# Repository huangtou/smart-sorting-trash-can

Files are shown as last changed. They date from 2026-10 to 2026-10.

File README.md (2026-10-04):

<div align="center">

# 智能分类垃圾桶系统

**基于 STM32F407 + YOLOv5 视觉识别的自动垃圾分类装置**







</div>

---

## 整机工作演示

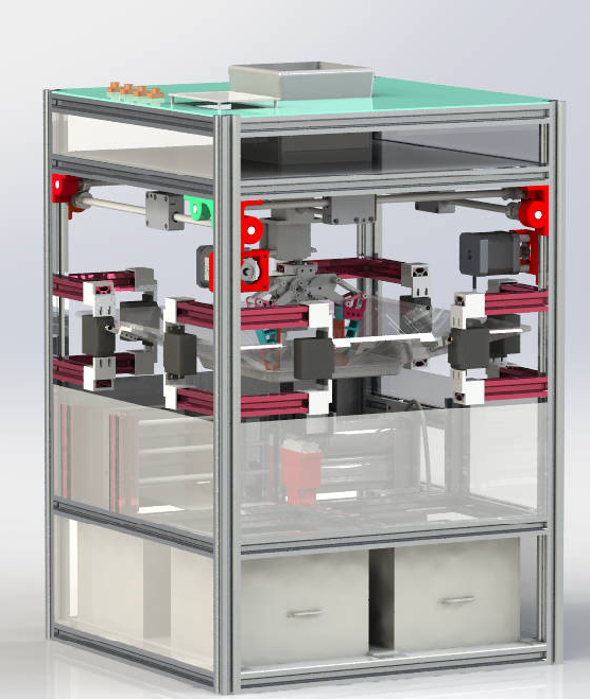
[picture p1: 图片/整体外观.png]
▶ 点击观看：垃圾分类演示视频（B站） (https://www.bilibili.com/video/BV1tyH76QEtr/)


**▶ [点击观看：垃圾分类演示视频（B站）](https://www.bilibili.com/video/BV1tyH76QEtr/)**

> 演示视频已上传 B 站，点击上方封面或链接即可在线观看；完整图文见 [十、效果展示](#十效果展示)。

---

## 目录

- [一、项目简介](#一项目简介)
- [二、主要功能](#二主要功能)
- [三、系统总体方案](#三系统总体方案)
- [四、硬件系统](#四硬件系统)
- [五、机械结构](#五机械结构)
- [六、软件架构](#六软件架构)
- [七、通信协议](#七通信协议)
- [八、快速开始](#八快速开始)
- [九、参数标定与调试](#九参数标定与调试)
- [十、效果展示](#十效果展示)
- [十一、常见问题](#十一常见问题)
- [十二、后续优化方向](#十二后续优化方向)

---

## 一、项目简介

本项目是一套面向**工程实践与创新能力大赛（工创赛）垃圾分类命题**的完整解决方案，实现"投放 → 识别 → 分拣 → 归仓 → 计数"的全流程自动化。

装置由 **视觉识别模块**、**STM32 主控**、**二维移动平台 + 机械臂**、**四分类仓** 与 **压缩机构** 组成：摄像头采集投入物图像，运行 YOLOv5 目标检测得到**垃圾类别**与**目标中心点坐标**，通过串口下发给 STM32；主控解算后根据场景选择**倾倒式投放**（单个物体）或**机械臂抓取投放**（多个物体），将垃圾投入对应的四分类仓，并实时累计各类垃圾数量。

仓库包含 **嵌入式控制程序、视觉识别程序、三维建模图纸、装配与调试资料**，可支撑从结构设计、加工装配到软件联调的完整复现。

---

## 二、主要功能

| 功能 | 说明 |
| :--- | :--- |
| **视觉自动识别** | 基于 YOLOv5 的目标检测，输出垃圾类别 ID 与目标中心点像素坐标 |
| **四分类自动分拣** | 有害垃圾 / 可回收垃圾 / 厨余垃圾 / 其他垃圾 四类自动归仓 |
| **双投放策略** | 单物体采用**翻板倾倒**，多物体采用**机械臂抓取**，兼顾效率与成功率 |
| **二维精确定位** | 由 2 路闭环步进电机驱动 XY 平台，将图像坐标解算为物理坐标并移动到位 |
| **闭环步进驱动** | 通过 CAN 总线控制 Emm_V5 闭环步进电机，支持双机同步运动 |
| **多自由度机械臂** | PCA9685 输出 16 路 PWM，驱动 9 路舵机完成回转 / 升降 / 夹取 / 翻板动作 |
| **分类计数与状态反馈** | 主控实时累计四类垃圾数量，并通过调试串口输出运行状态 |
| **压缩机构（预留）** | TIM4 双路 PWM + 方向 IO + 光电限位，用于桶内垃圾压缩与到位检测 |
| **一键启动** | 独立按键触发投放流程，便于现场演示与调试 |

---

## 三、系统总体方案

### 3.1 系统架构

```
┌──────────────┐   USART3(9600)    ┌──────────────────┐
│              │  类别/坐标/数量    │                  │
│  MaixCam     │ ────────────────► │   STM32F407ZGT6  │
│  视觉模块     │ ◄────────────────  │     主控          │
│ (YOLOv5)     │   请求指令 "FS"    │                  │
└──────────────┘                   └────────┬─────────┘
                                            │
             ┌──────────────────────────────┼──────────────────────────┐
             │                              │                          │
      CAN1(500kbps)                  软件 I2C(PC7/PC8)          TIM4 PWM + GPIO
             │                              │                          │
    ┌────────▼────────┐          ┌──────────▼─────────┐      ┌─────────▼────────┐
    │ Emm_V5 闭环步进  │          │     PCA9685        │      │  压缩机构 / 限位   │
    │  #1  #2 (X/Y)   │          │  16 路 PWM 舵机板   │      │  光电开关 ×3      │
    └────────┬────────┘          └──────────┬─────────┘      └──────────────────┘
             │                              │
      XY 二维移动平台              机械臂(升降/回转/夹爪) + 分类翻板 + 仓盖
```

### 3.2 工作时序

```
上电
 │
 ├─ 外设初始化：GPIO / DMA / USART1 / USART3 / TIM4 / CAN1
 ├─ 步进电机初始化、PCA9685 初始化(50Hz)
 ├─ 开启 USART3 空闲中断 + DMA 接收
 ├─ 舵机复位（合盖、平台归位）
 ▼
┌──────────── 主循环 ────────────┐
│  1. 发送 "FS" 请求视觉识别       │
│  2. 等待视觉返回 type / x / y / n │
│  3. 判断数量 n                   │
│     ├─ n = 1 → 翻板倾倒投放      │
│     └─ n ≥ 2 → 机械臂抓取投放    │
│  4. 类别计数 n_0 ~ n_3 自增      │
│  5. 机构复位，返回步骤 1          │
└────────────────────────────────┘
```

---

## 四、硬件系统

### 4.1 主控与外设资源分配

主控：**STM32F407ZGT6**（LQFP144，168 MHz，HSE 8 MHz → PLL 168 MHz；APB1 42 MHz / APB2 84 MHz）

| 外设 | 引脚 | 参数 | 用途 |
| :--- | :--- | :--- | :--- |
| **USART1** | PA9 / PA10 | 9600-8-N-1，DMA2_Stream2 | 调试串口（`printf` 已重定向），运行日志输出 |
| **USART3** | PC10 / PC11 | 9600-8-N-1，DMA1_Stream1 + 空闲中断 | 与视觉模块双向通信 |
| **CAN1** | PB8 / PB9 | 500 kbps（42 MHz ÷14 ÷6 TQ） | Emm_V5 闭环步进电机指令 |
| **TIM4 CH1** | PB6 | PWM 1 kHz（PSC 83 / ARR 1000） | 压缩机构驱动 |
| **TIM4 CH2** | PB7 | PWM 1 kHz | 辅助执行机构调速 |
| **软件 I2C** | PC7(SDA) / PC8(SCL) | 推挽 + 上拉 | PCA9685 舵机控制板 |
| **GPIO 输出** | PC4 / PC5 / PC9 / PA8 | 推挽输出 | 电机方向 / 使能控制 |
| **GPIO 输入** | PG3 / PG5 / PG7 | 上拉输入（`GD3` / `GD2` / `GD1`） | 光电开关，用于到位检测与限位 |
| **GPIO 输入** | PB3（`key_s1`） | 上拉输入 | 启动 / 触发按键 |

### 4.2 舵机通道分配（PCA9685，50 Hz）

| 通道 | 代码变量 | 参考值 | 机械含义（以实际装配为准） |
| :---: | :--- | :---: | :--- |
| 0 | `angle_0` | 130 | 分类翻板 A（外摆 `+45`） |
| 1 | `angle_1` | 130 | 分类翻板 B（配合通道 0 组合出四种倾倒方向） |
| 2 | `angle_2` | 120 | 机械臂夹爪（夹紧 `+50`） |
| 3 | `angle_3` | 152 | 机械臂升降（下压 `-90`） |
| 4 | `angle_4` | 250 | 机械臂回转（转位 `-90`） |
| 5 | `angle_5` | 140 | 辅助执行机构（仓盖 / 挡板联动） |
| 6 | `angle_6` | 125 | 辅助执行机构 |
| 7 | `angle_7` | 170 | 辅助执行机构 |
| 8 | `angle_8` | 70 | 辅助执行机构 |

> 四路倾倒姿态由通道 0/1 的 `±45°` 组合而成，对应四个分类仓；所有角度均为 **270° 舵机映射值**（`setAngle270`），装机后需逐路标定。

### 4.3 视觉模块

| 项目 | 规格 |
| :--- | :--- |
| 主控 | **MaixCam**（MaixPy 运行环境） |
| 算法 | **YOLOv5**（MaixHub 训练，产出 `.mud` 模型） |
| 接口 | `/dev/ttyS0`，9600-8-N-1 |
| 输出 | 类别 ID、目标中心点像素坐标 `(x, y)`、目标数量 `n` |

> 视觉方案共迭代两版：**MaixCam 版** 与 **树莓派版**，二者原理一致（YOLO 检测 → 下发类别与坐标 → STM32 解算执行）。出于部署便利性考虑，**本仓库开源 MaixCam 版本**。

### 4.4 主要器件清单

| 类别 | 器件 |
| :--- | :--- |
| 主控 | STM32F407ZGT6 最小系统板 |
| 视觉 | MaixCam（含摄像头与显示屏） |
| 舵机驱动 | PCA9685 16 路 PWM 舵机控制板 |
| 舵机 | 270° 舵机 ×9（含 MG995 等） |
| 步进 | Emm_V5 闭环步进电机 ×2（CAN 接口，地址 1 / 2） |
| 传动 | 2020 铝型材、GT2 同步带与皮带轮、MGN9 线轨与滑块、6 mm / 8 mm 光轴、直线轴承 |
| 传感 | 光电开关 ×3 |
| 结构 | 3D 打印件（滑块、轴座、支架）+ 铝型材框架 + 亚克力 / 钣金挡板 |

---

## 五、机械结构

整机采用 **铝型材框架 + 3D 打印连接件** 的方案，自下而上分为四层：

1. **框架层**：2020 铝型材搭建主体框架，脚码连接，配侧板、护板与外层挡板。
2. **移动平台层**：X / Y 双轴由闭环步进电机经 GT2 同步带驱动，光轴 + 直线轴承 / MGN9 线轨导向，构成二维定位平台。
3. **执行层**：平台下方悬挂机械臂（回转 + 升降 + 夹爪），配合四组分类翻板完成投放。
4. **存储层**：四个独立分类仓，底部布置压缩机构（挡板 + 推杆），配合光电开关实现到位检测。

| 图纸 | 文件 |
| :--- | :--- |
| 总装配体 | `建模/第五版.SLDASM`、`建模/装配体2.SLDASM` |
| 零件 | `建模/*.SLDPRT`（铝型材、光轴、滑块、支架、挡板、仓体等 65 个零件） |
| 工程图 | `建模/相关资料/工程图2.pdf`、`工程图333.dwg`、`工程图.jpg` |
| 说明文档 | `建模/相关资料/垃圾分类命题文档（改）.doc` |

---

## 六、软件架构

### 6.1 目录结构

```
工创垃圾桶/
├─ README.md                  # 本文件
├─ .gitignore                 # Git 忽略规则
│
├─ stm32控制/                 # 嵌入式控制程序
│  └─ stm32_hal/
│     ├─ gongchuang.ioc       # STM32CubeMX 工程配置（引脚 / 时钟 / 外设）
│     ├─ Core/                # CubeMX 自动生成：时钟、GPIO、DMA、USART、TIM、CAN
│     ├─ Drivers/             # STM32F4 HAL 库 + CMSIS（不入库，见下方说明）
│     ├─ hard_with_sofa/      # ★ 应用层驱动与业务逻辑（本项目核心代码）
│     └─ MDK-ARM/             # Keil uVision 工程（gongchuang.uvprojx）
│
├─ 视觉方案/                   # 视觉识别程序
│  ├─ gongc.py                # MaixCam 端 YOLOv5 检测 + 串口通信
│  └─ readme.txt              # 视觉方案说明
│
├─ 建模/                      # SolidWorks 三维模型
│  ├─ 第五版.SLDASM / 装配体2.SLDASM
│  ├─ *.SLDPRT                # 全部零件
│  └─ 相关资料/                # 工程图(PDF/DWG)、渲染图、命题文档
│
└─ 图片/                      # 效果展示与演示资料
   ├─ 整体外观.png / 内部结构图.png
   ├─ 垃圾桶装配.png / 垃圾桶装配图.png
   ├─ 识别.jpg / 数据集采集.png
   └─ 视频演示.mp4
```

### 6.2 应用层模块说明（`hard_with_sofa/`）

| 文件 | 说明 |
| :--- | :--- |
| `sys.h` | 公共头文件汇总；位带操作宏（`PAout/PAin`…）；光电传感器 `GD1/GD2/GD3` 宏定义 |
| `delay.c/.h` | 基于指令循环的软件延时 `for_delay_us()` / `for_delay_ms()`（按 168 MHz 主频标定） |
| `PCA9685.c/.h` | 软件 I2C（PC7/PC8）+ PCA9685 驱动，`PCA9685_Init()`、`PCA9685_setPWM()`、`setAngle90/180/270/360()` |
| `Emm_V5.c/.h` | Emm_V5 闭环步进电机 CAN 指令集：位置控制、速度控制、同步运动、急停、回零、参数读取 |
| `MOTOR.c/.h` | 平台运动封装：`move()` 双轴移动、`compress()` 压缩控制、`GD()` 限位读取 |
| `myusart.c/.h` | 串口 DMA + 空闲中断接收、视觉数据帧解析状态机、`printf` 重定向、`UART3_SendString()` |
| `capture.c/.h` | **核心业务逻辑**：`control()` 机构动作组合、`initial()` 自动分拣主流程 |

### 6.3 开发环境

| 项目 | 版本 / 工具 |
| :--- | :--- |
| 单片机 | STM32F407ZGT6 |
| 固件库 | STM32Cube FW_F4 **V1.28.1** |
| 配置工具 | STM32CubeMX（打开 `gongchuang.ioc`） |
| 编译工具 | **Keil MDK-ARM V5.27+**（ARMCC5） |
| 下载调试 | ST-Link / CMSIS-DAP（SWD） |
| 视觉端 | MaixCam + MaixPy + MaixHub 训练平台 |
| 建模 | SolidWorks（2020 及以上可打开 `.SLDPRT` / `.SLDASM`） |

---

## 七、通信协议

### 7.1 视觉 → 主控（USART3，9600-8-N-1）

采用**定长帧 + 帧头帧尾校验**，共 **11 字节，小端序**（对应 MaixPy 的 `struct.pack("<bbhhhhb", ...)`）：

| 字节偏移 | 0 | 1 | 2 ~ 3 | 4 ~ 5 | 6 ~ 7 | 8 ~ 9 | 10 |
| :---: | :---: | :---: | :---: | :---: | :---: | :---: | :---: |
| **含义** | 帧头 | 帧头 | 类别 `type` | 中心 X `x` | 中心 Y `y` | 数量 `n` | 帧尾 |
| **取值** | `0x2C` | `0x2E` | int16 | int16 | int16 | int16 | `0x5B` |

主控侧由 `process_received_data3()` 以**四状态机**（等帧头 → 校验第二字节 → 收数据 → 校验帧尾）解析，解析成功后置位 `cam_flag` 并更新全局变量 `type / x / y / n`。

### 7.2 主控 → 视觉（USART3）

| 指令（ASCII） | 含义 | 使用场景 |
| :--- | :--- | :--- |
| `FS` | 请求一次识别并回传结果 | 自动分拣主流程中轮询 |
| `FSSJ` | 请求发送识别结果数据 | 抓取流程中逐次请求目标数据 |

视觉端收到任意数据后，将当前帧检测结果回发一帧。

### 7.3 类别映射表

主控侧保留 14 个类别 ID 到四类垃圾的映射（见 `capture.c`，可按自己的模型类别自行修改）：

| 类别 ID | 垃圾类别 | 计数变量 |
| :--- | :--- | :--- |
| 0 / 1 / 11 / 12 | 有害垃圾 | `n_0` |
| 2 / 3 / 9 | 可回收垃圾 | `n_1` |
| 4 / 5 / 6 / 10 / 13 | 厨余垃圾 | `n_2` |
| 7 / 8 | 其他垃圾 | `n_3` |

本仓库附带的 MaixCam 模型为 **4 类**（`电池 / 易拉罐 / 石头 / 胡萝卜`），视觉端按 `class_id + 1` 下发 `type = 1 ~ 4`；若更换或扩充模型，请同步修改 `capture.c` 中的映射关系。

### 7.4 步进电机（CAN1，500 kbps）

| 指令函数 | 功能 |
| :--- | :--- |
| `Emm_V5_Pos_Control(addr, dir, vel, acc, clk, raF, snF)` | 位置模式控制（写入目标脉冲） |
| `Emm_V5_Synchronous_motion(addr)` | 触发多机同步启动 |
| `Emm_V5_Stop_Now(addr, snF)` | 立即停止 |
| `Emm_V5_En_Control` / `Emm_V5_Vel_Control` | 使能 / 速度模式 |
| `Emm_V5_Origin_Trigger_Return` | 触发回零 |

X / Y 双轴分别使用地址 **1** 与 **2**，先分别下发位置指令，再调用同步运动，实现双轴协同。

---

## 八、快速开始

### 8.1 硬件准备与接线

| 模块 | 接线 |
| :--- | :--- |
| 视觉模块 | MaixCam `ttyS0` TX → `PC11(USART3_RX)`；RX → `PC10(USART3_TX)`；**共地** |
| PCA9685 | `SDA → PC7`，`SCL → PC8`，VCC/GND 共地，舵机电源独立供电 |
| 步进电机 | CAN_H / CAN_L → `PB8 / PB9`，总线上加 **120 Ω 终端电阻**，地址设为 1 与 2 |
| 压缩机构 | TIM4 `PB6 / PB7` → 驱动模块 PWM；`PC4 / PC5 / PC9 / PA8` → 方向与使能 |
| 光电开关 | `PG3 / PG5 / PG7`（上拉输入，触发电平按传感器类型确认） |
| 启动按键 | `PB3`（上拉输入，按下接低） |

### 8.2 编译与下载（STM32）

1. 安装 **Keil MDK-ARM V5** 及 STM32F4 器件支持包（DFP）。
2. **（首次克隆必做）** 用 STM32CubeMX 打开 `gongchuang.ioc` → **Generate Code**，补齐未入库的 `Drivers/` 固件库。
3. 打开 `stm32控制/stm32_hal/MDK-ARM/gongchuang.uvprojx`。
4. 确认 `Options for Target → C/C++ → Include Paths` 包含：
   ```
   Core/Inc  Drivers/STM32F4xx_HAL_Driver/Inc  Drivers/CMSIS/Device/ST/STM32F4xx/Include
   Drivers/CMSIS/Include  hard_with_sofa
   ```
5. 点击 **Rebuild** 编译，用 ST-Link / CMSIS-DAP 经 SWD **Download**。
6. 修改引脚或外设参数：用 STM32CubeMX 打开 `gongchuang.ioc` 重新生成代码（用户代码写在 `USER CODE BEGIN/END` 之间，不会被覆盖）。

> 📦 **重要：`Drivers/` 未入库。** 为控制仓库体积，STM32 固件库（HAL + CMSIS，约 20 MB）已由 `.gitignore` 排除，因为它可由 CubeMX **100% 还原**。
>
> **克隆本仓库后的第一步**：用 STM32CubeMX 打开 `stm32控制/stm32_hal/gongchuang.ioc` → 点击 **Generate Code**，生成 `Drivers/` 后再用 Keil 打开工程编译即可。

### 8.3 视觉端部署（MaixCam）

1. 在 [MaixHub](https://maixhub.com) 训练 YOLOv5 模型，或使用自备模型，得到 `.mud` 文件。
2. 将模型上传至 MaixCam，例如 `/root/models/model_167094.mud`。
3. 修改 `视觉方案/gongc.py` 中的模型路径：
   ```python
   detector = nn.YOLOv5(model="/root/models/model_167094.mud", dual_buff=True)
   ```
4. 将 `gongc.py` 导入 MaixCam 并运行，屏幕会实时显示检测框、类别与置信度。
5. 检测阈值可在 `detector.detect(img, conf_th=0.5, iou_th=0.45)` 中调整。

> ⚠️ **模型文件（`.mud`）未包含在仓库中**，需自行训练或自备。采集数据集时建议覆盖实际赛题的全部类别，并保持光照、角度、遮挡的多样性。

### 8.4 运行

1. 先给舵机与步进电机独立供电，再给主控上电（避免上电瞬间舵机抖动）。
2. 上电后机构自动复位：合盖 → 平台归位 → 夹爪张开。
3. 投入垃圾后，主控自动轮询视觉模块，识别完成后执行投放并更新计数。
4. 调试阶段可通过 **USART1（PA9/PA10，9600）** 查看运行日志。

---

## 九、参数标定与调试

首次装机需按实际尺寸标定以下参数（位于 `main.c` 与 `capture.c`）：

| 参数 | 默认值 | 说明 |
| :--- | :--- | :--- |
| `strat_x` / `end_x` | 220 / 480 | 图像 X 方向有效区间（像素） |
| `start_y` / `end_y` | 125 / 390 | 图像 Y 方向有效区间（像素） |
| `err_x` / `err_y` | `4.0/220` / `3.8/265` | 像素坐标 → 物理位移的比例系数 |
| `x_b` / `x_e` | 4.7 / 0.9 | 平台 X 轴起止物理坐标 |
| `y_b` / `y_e` | 0 / -3.5 | 平台 Y 轴起止物理坐标 |
| `x_count` / `y_count` | 4.5 / 4.5 | 平台行程 |
| `3200` | — | 每单位位移对应脉冲数（`Emm_V5_Pos_Control` 的 `clk`） |
| `angle_0 ~ angle_8` | 130/130/120/152/250/140/125/170/70 | 9 路舵机中位角度 |

**标定建议**

- **视觉标定**：在平台行程的四角放置标定物，记录像素坐标与实际位移，反解 `err_x` / `err_y`。
- **舵机标定**：逐路调用 `setAngle270()` 观察机构极限位，避免堵转烧毁；把安全中位写回 `angle_x`。
- **步进标定**：先单轴低速试运行，确认方向（`dir`）与限位（`GD1/GD2`）逻辑正确后再联动。

---

## 十、效果展示

### 10.1 演示视频

**垃圾分类演示视频（B站）**

▶ 点击观看：垃圾分类演示视频 (https://www.bilibili.com/video/BV1tyH76QEtr/)

**▶ [点击观看：垃圾分类演示视频（B站）](https://www.bilibili.com/video/BV1tyH76QEtr/)**

### 10.2 图片

| 内容 | 文件 |
| :--- | :--- |
| 整体外观 | `图片/整体外观.png` |
| 内部结构 | `图片/内部结构图.png` |
| 装配图 | `图片/垃圾桶装配.png`、`图片/垃圾桶装配图.png` |
| 识别效果 | `图片/识别.jpg` |
| 数据集采集 | `图片/数据集采集.png` |
| 渲染图 / 工程图 | `建模/相关资料/` |

整体外观

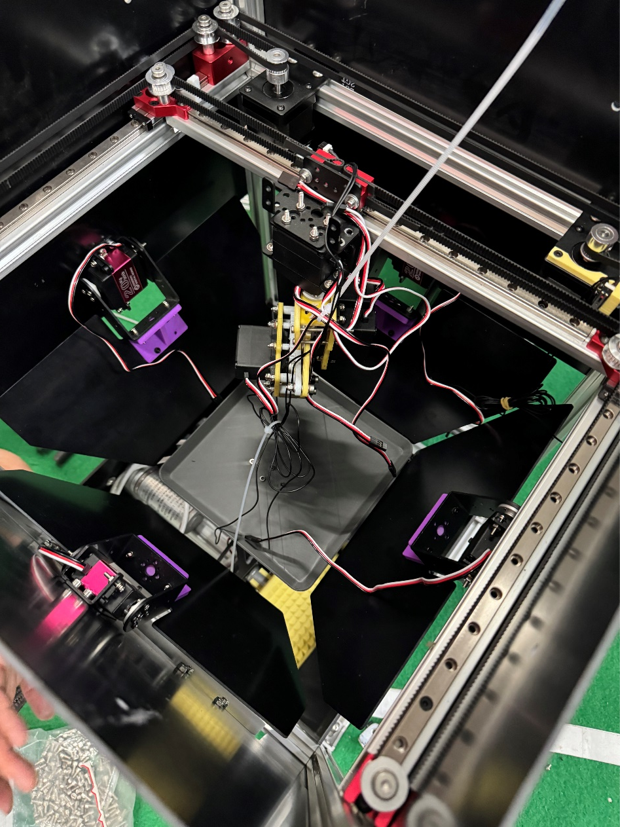
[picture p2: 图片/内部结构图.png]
内部结构图


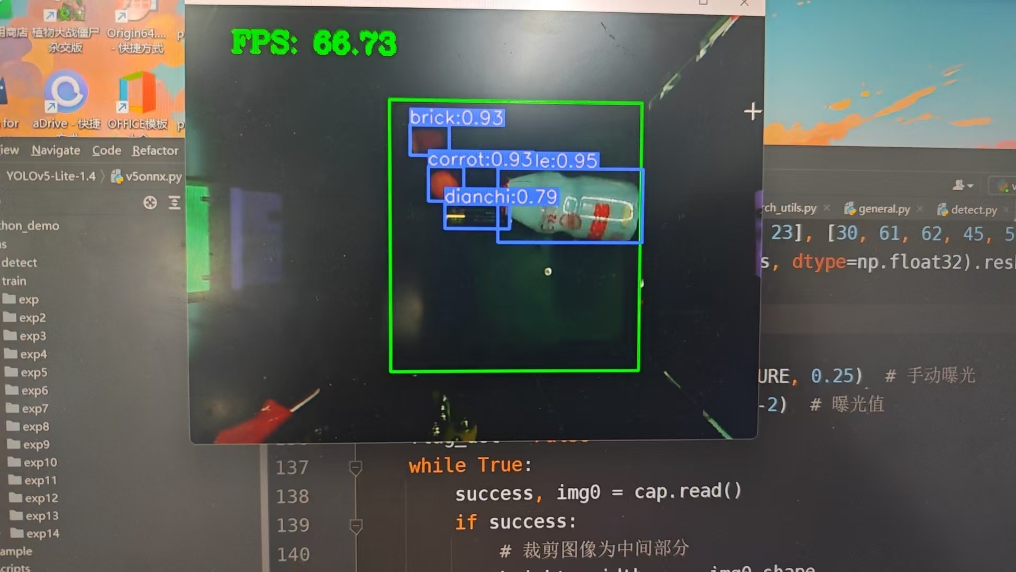
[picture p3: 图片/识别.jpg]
识别效果


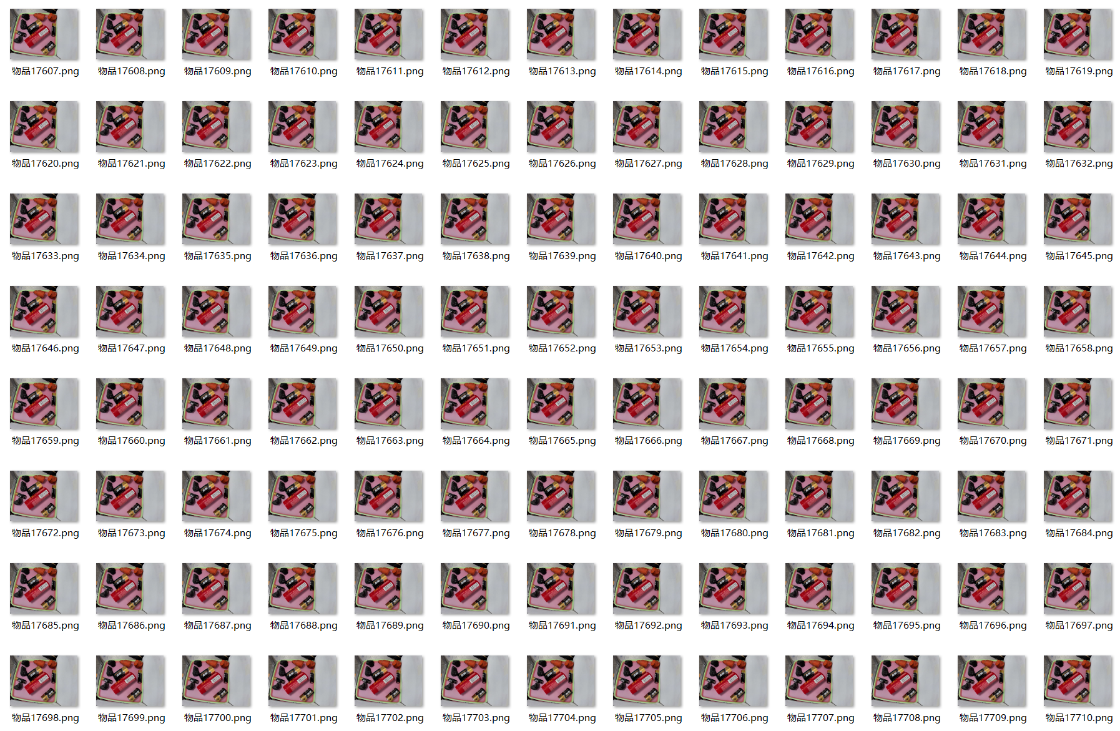
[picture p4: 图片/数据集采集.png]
数据集采集


---

## 十一、常见问题

<details>
<summary><b>Q1：Keil 编译报 "No such file or directory"</b></summary>

检查 `Options for Target → C/C++ → Include Paths` 是否包含 `hard_with_sofa`、`Core/Inc` 及 `Drivers` 下相关目录（见 8.2）。
</details>

<details>
<summary><b>Q2：视觉模块无数据返回</b></summary>

1. 确认波特率一致（双方均 9600-8-N-1）；
2. 确认 TX / RX 交叉连接且**共地**；
3. 用调试串口打印 `type / x / y / n`，确认帧头 `0x2C 0x2E` 与帧尾 `0x5B` 是否解析成功；
4. 确认 MaixCam 端已正确加载模型路径。
</details>

<details>
<summary><b>Q3：步进电机不动作或方向相反</b></summary>

1. 确认 CAN 波特率 500 kbps，总线两端接 120 Ω 终端电阻；
2. 确认两台电机地址分别为 1 与 2，且未冲突；
3. 方向相反时修改 `move()` 中的 `direr` 逻辑或调换电机相序；
4. 确认 `Emm_V5_Pos_Control` 后调用了 `Emm_V5_Synchronous_motion(0)` 触发同步。
</details>

<details>
<summary><b>Q4：舵机角度不对或抖动</b></summary>

1. 确认 PCA9685 频率为 50 Hz（`PCA9685_Init(50, 0)`）；
2. 舵机电源需独立供电且与控制板共地；
3. 用 `setAngle270()` 重新标定 `angle_0 ~ angle_8`；
4. 抖动多由供电不足或机械卡滞引起，检查机构配合间隙。
</details>

<details>
<summary><b>Q5：识别准确率不足</b></summary>

1. 扩充数据集（各类别不少于数百张，覆盖不同光照 / 角度 / 遮挡）；
2. 调整 `conf_th` / `iou_th`；
3. 确认摄像头焦距与安装角度，使检测区域完整覆盖投放区。
</details>

---

## 十二、后续优化方向

- [ ] 扩充垃圾类别数量，提升小目标与遮挡场景下的识别精度
- [ ] 将阻塞式延时改为**状态机 + 定时器调度**，提升系统实时性与响应性
- [ ] 增加**满桶检测**与**自动压缩**的完整联动逻辑
- [ ] 增加投放成功率自检与异常处理（卡料、夹取失败重试）
- [ ] 上位机 / 移动端数据可视化，统计分类趋势
- [ ] 结构轻量化与模块化，缩短装配与维护时间
- [ ] 引入 ROS / 树莓派方案，实现更丰富的场景扩展

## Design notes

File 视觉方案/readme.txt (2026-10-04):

视觉方案一共做了两版 版本一是采用maixcam 另一个版本是采用树莓派
二者基本原理相同 均是采用yolo检查垃圾类型 发送类别和中心点坐标给stm32
stm32端解算 若单物品采用倾倒 多物体采用机械臂抓取
本次开源考录到使用方便性开源maixcam版本 代码如gongc所示，需要将模型和代码导入maixcam中并修改代码中模型路径

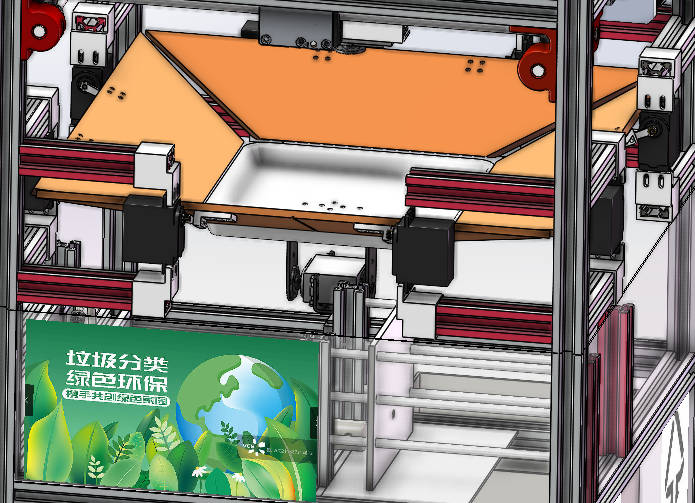
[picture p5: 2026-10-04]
建模/相关资料/侧面.jpg

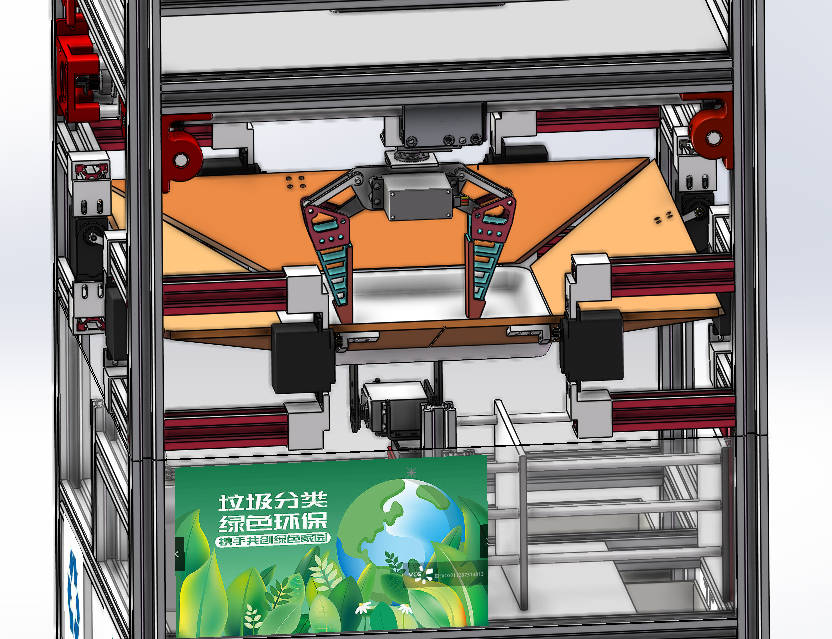
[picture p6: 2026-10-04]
建模/相关资料/抓手.jpg

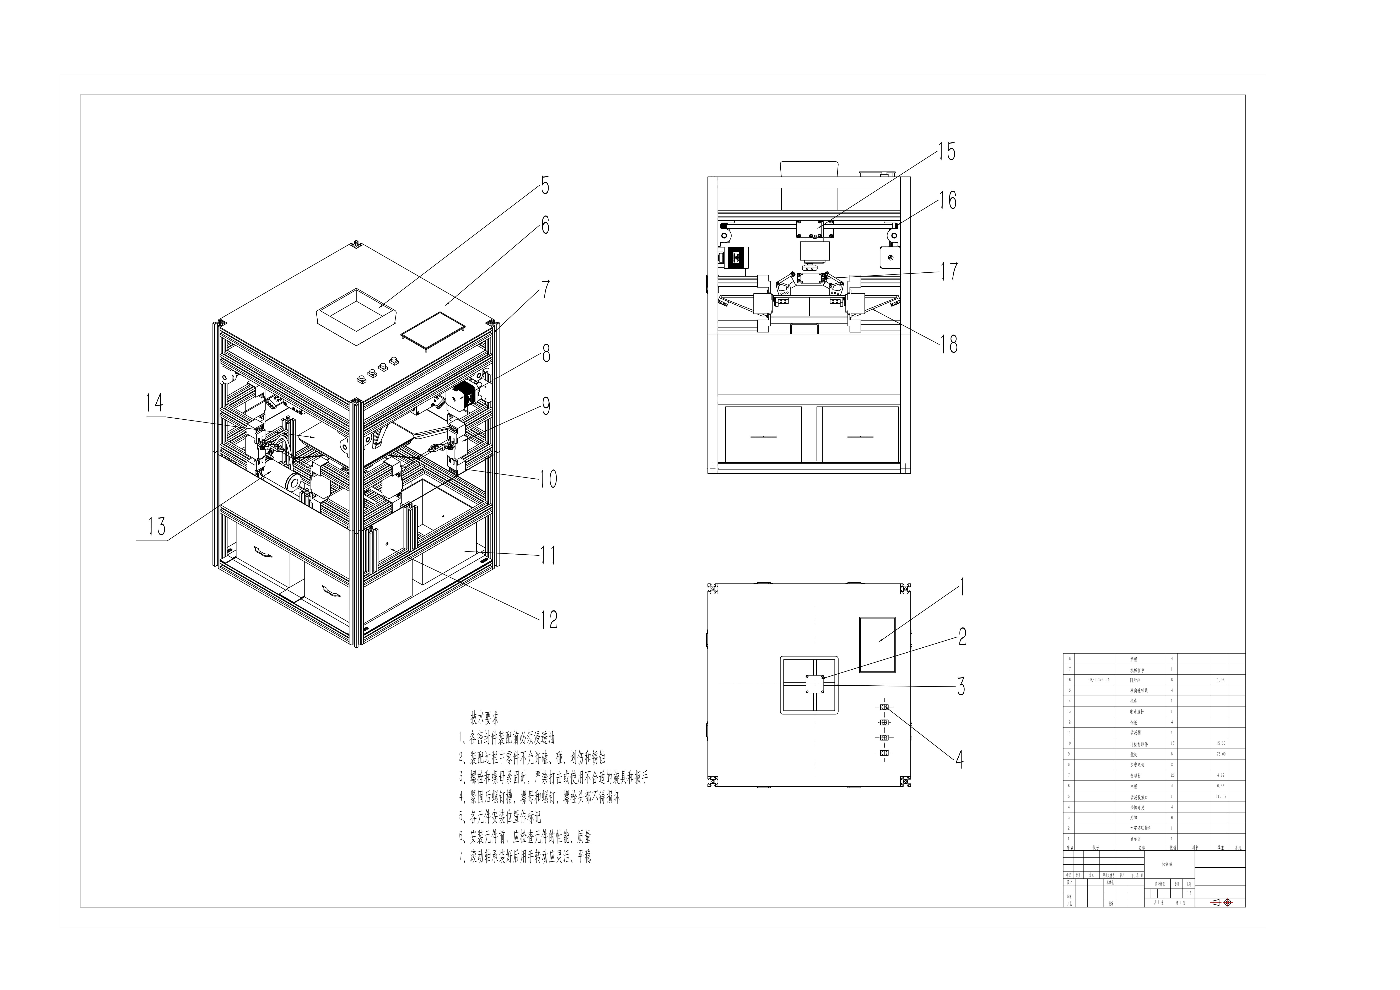
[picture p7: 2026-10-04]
建模/相关资料/工程图.jpg

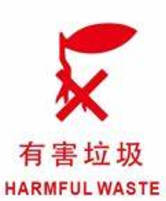
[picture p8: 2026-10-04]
建模/相关资料/有害垃圾.jpg

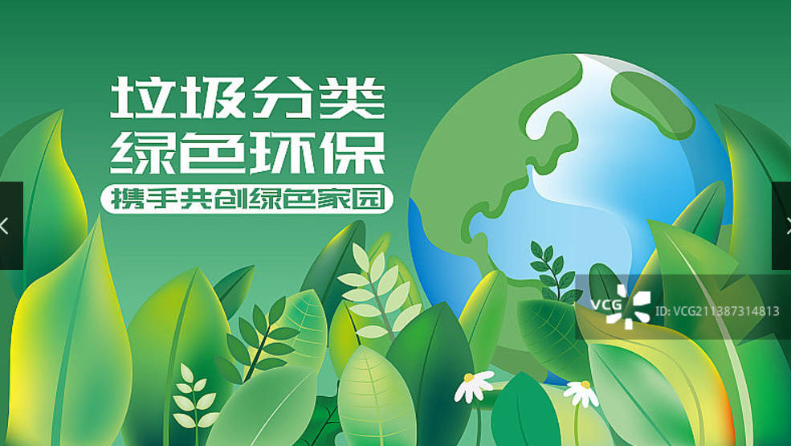
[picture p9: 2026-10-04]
建模/相关资料/宣传图.jpg

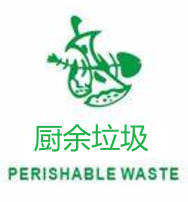
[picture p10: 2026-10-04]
建模/相关资料/厨余垃圾.jpg

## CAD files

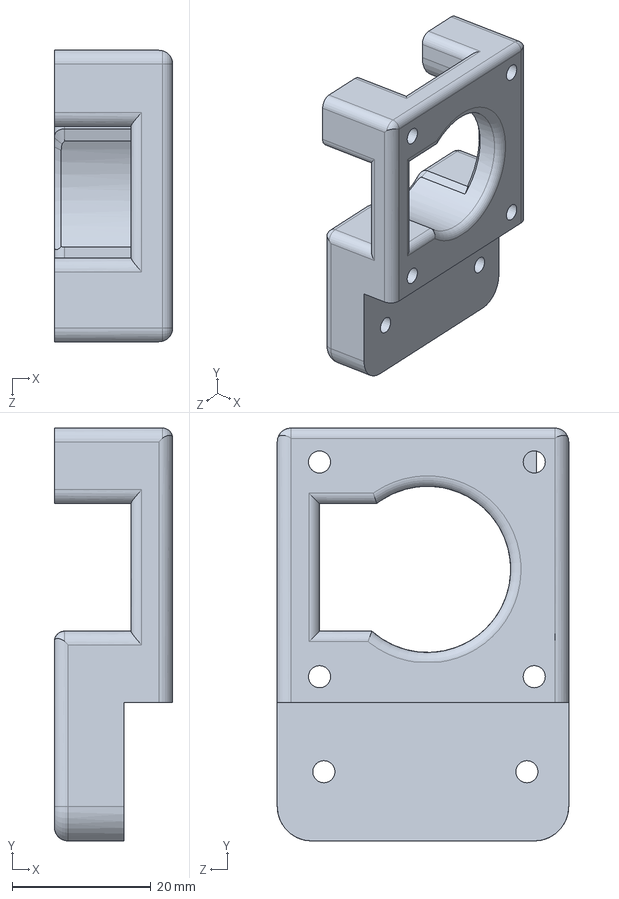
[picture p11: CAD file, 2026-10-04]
建模/步进电机支架2.SLDPRT
17.1 x 59.6 x 42.1 mm

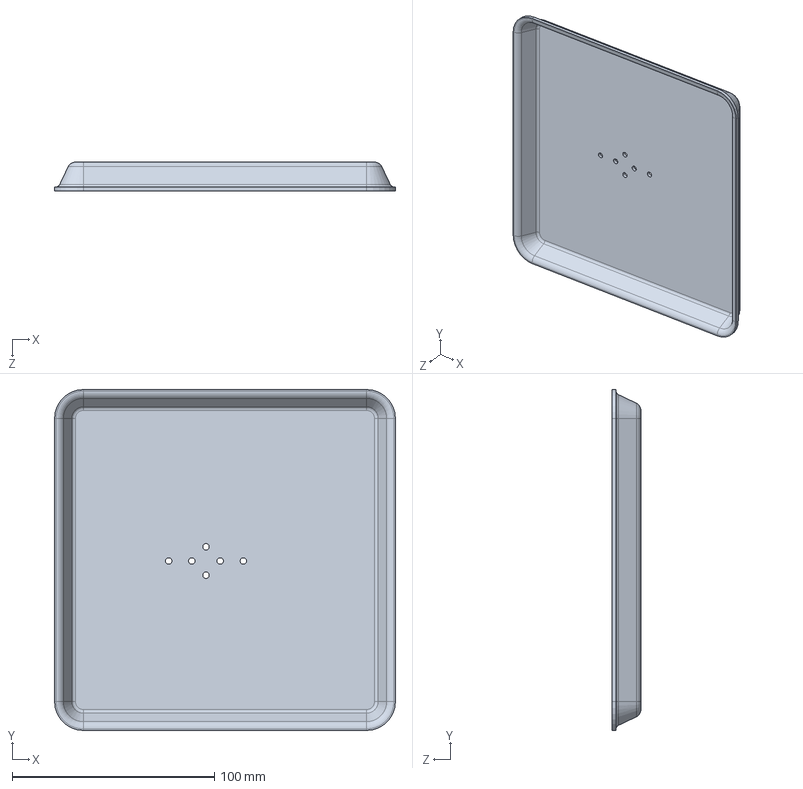
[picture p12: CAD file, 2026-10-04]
建模/托盘.SLDPRT
168.8 x 168.8 x 14.3 mm

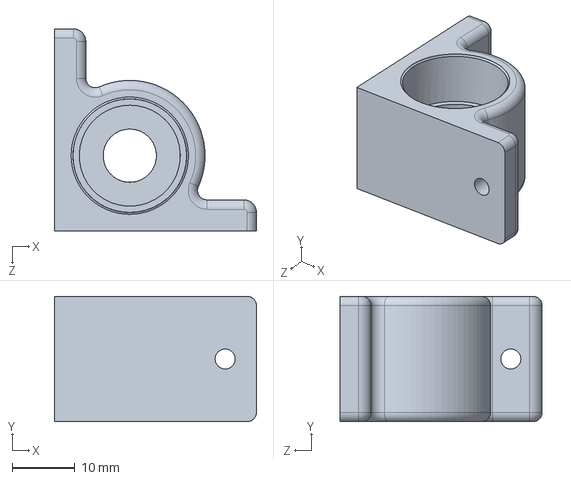
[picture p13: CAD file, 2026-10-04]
建模/x-axis front right（打印件）.SLDPRT
32.2 x 20.0 x 32.3 mm

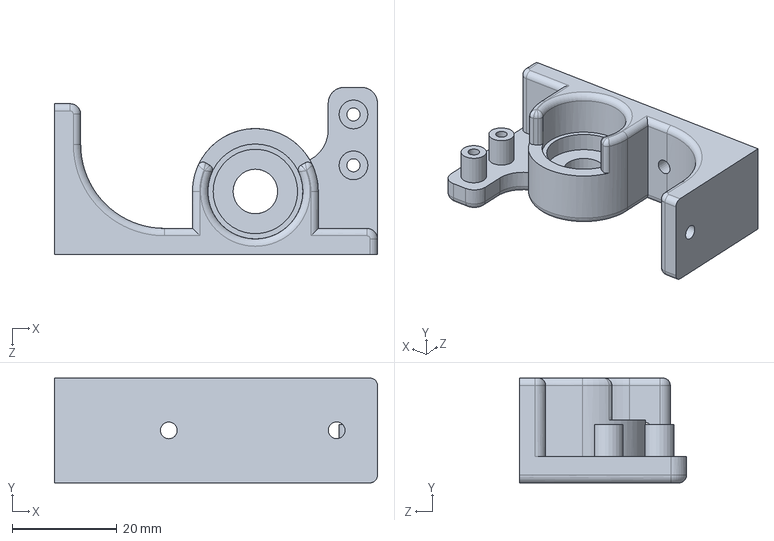
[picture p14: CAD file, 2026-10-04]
建模/x-axis rear left(打印件).SLDPRT
61.6 x 20.0 x 31.9 mm

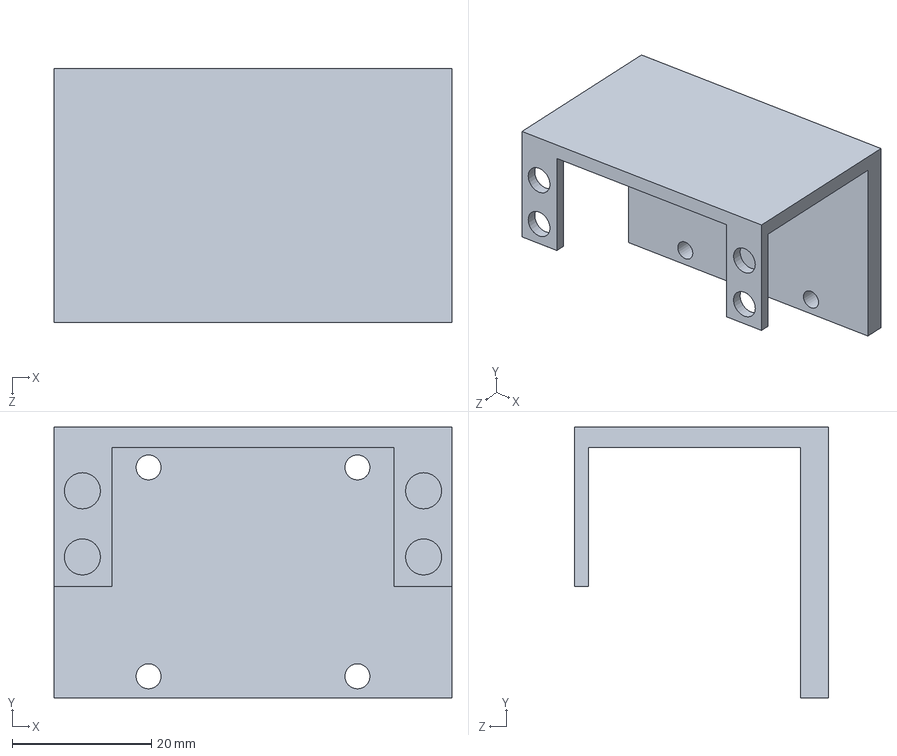
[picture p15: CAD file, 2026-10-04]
建模/垂直舵机支架.SLDPRT
57.2 x 38.9 x 36.5 mm

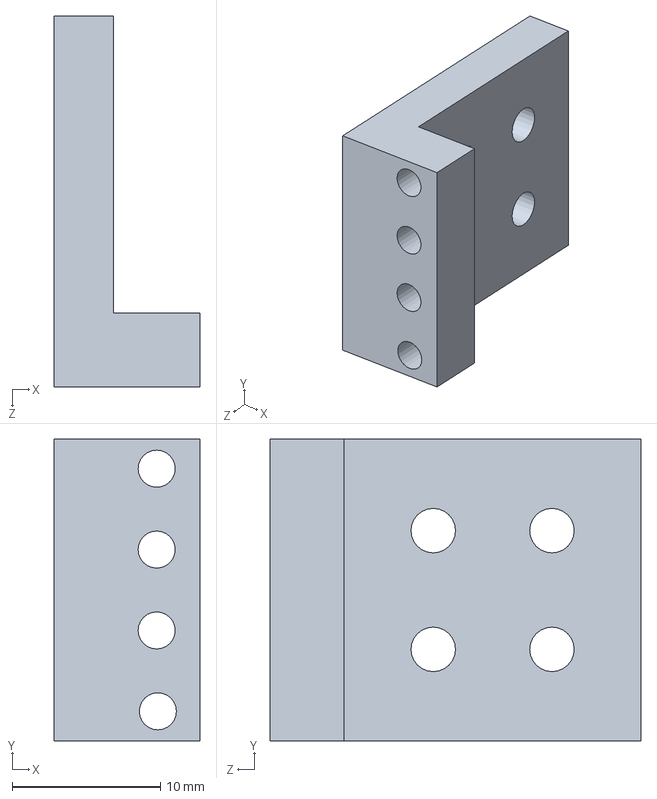
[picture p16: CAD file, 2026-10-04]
建模/挡板固定.SLDPRT
9.84 x 20.3 x 25.0 mm

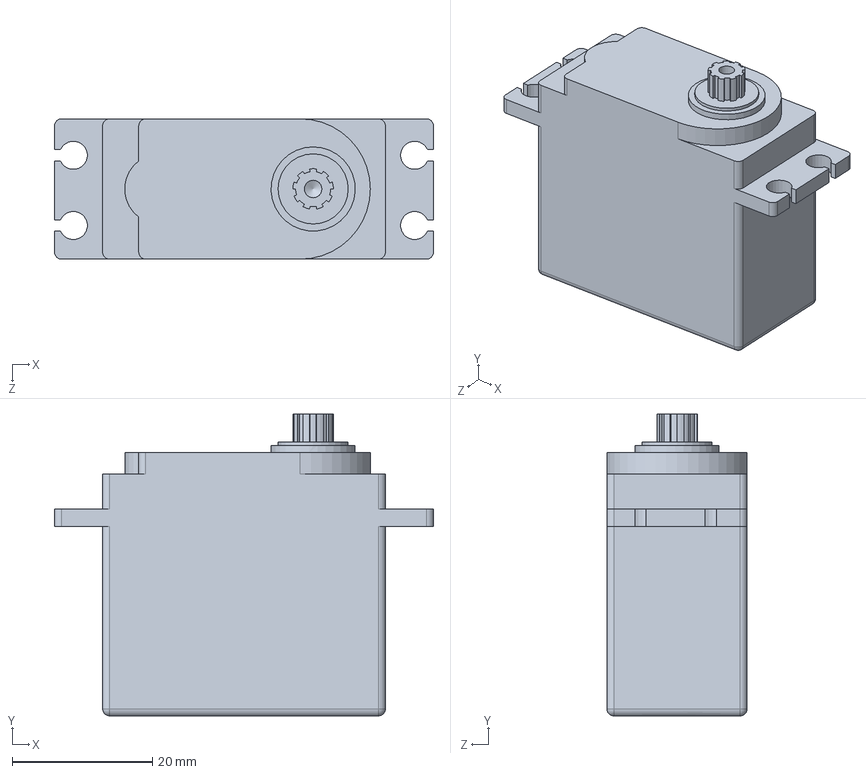
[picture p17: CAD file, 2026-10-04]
建模/MG995舵机(压缩挡板舵机).SLDPRT
54.0 x 43.0 x 20.0 mm

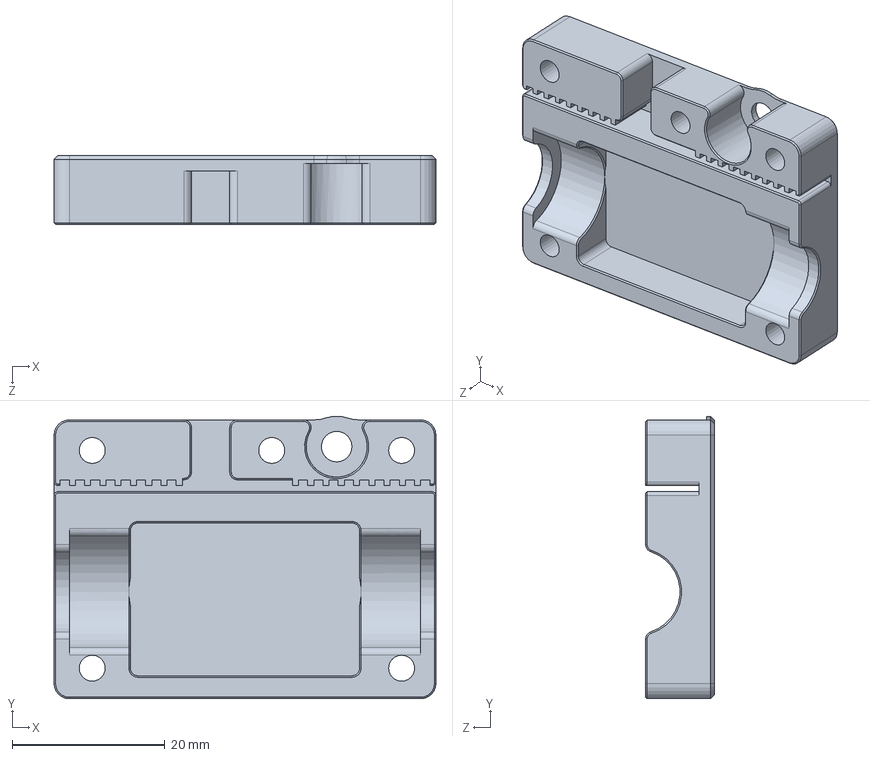
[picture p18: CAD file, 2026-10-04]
建模/滑块_左.SLDPRT
50.0 x 37.0 x 9.00 mm

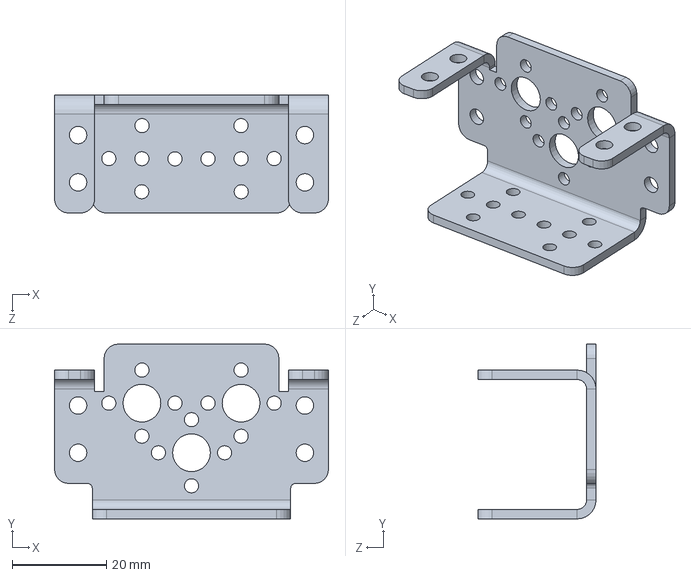
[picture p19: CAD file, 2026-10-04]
建模/电机架.SLDPRT
58.0 x 37.0 x 25.0 mm

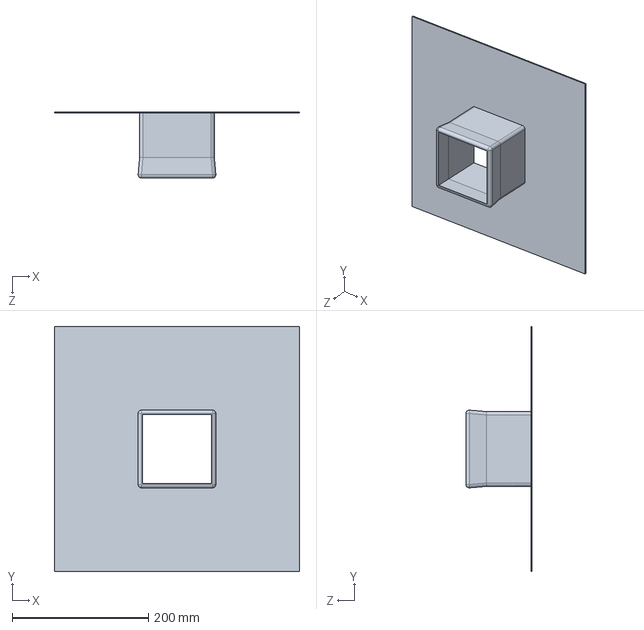
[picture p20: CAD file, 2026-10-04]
建模/夹层板.SLDPRT
360.0 x 360.0 x 97.4 mm

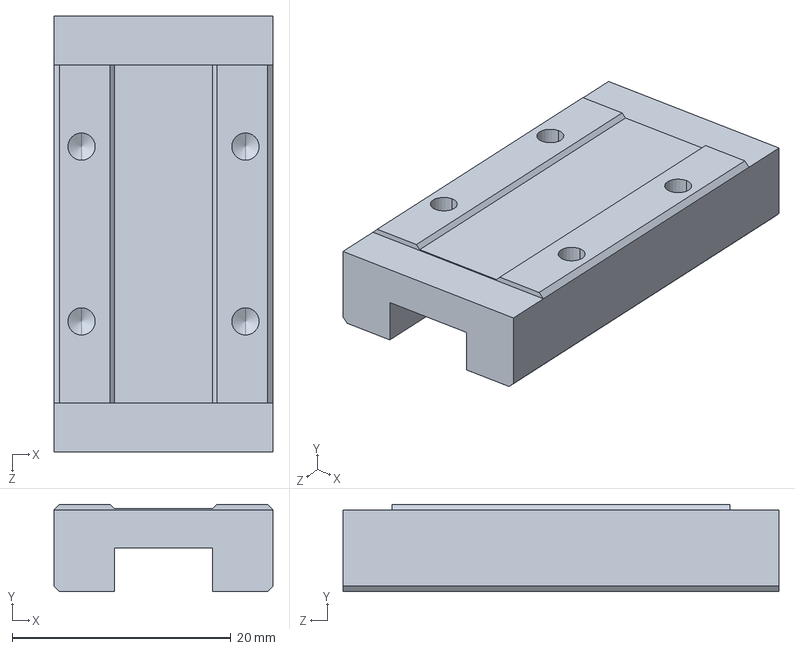
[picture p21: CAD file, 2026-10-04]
建模/MGN9H滑块.SLDPRT
20.0 x 8.00 x 39.9 mm

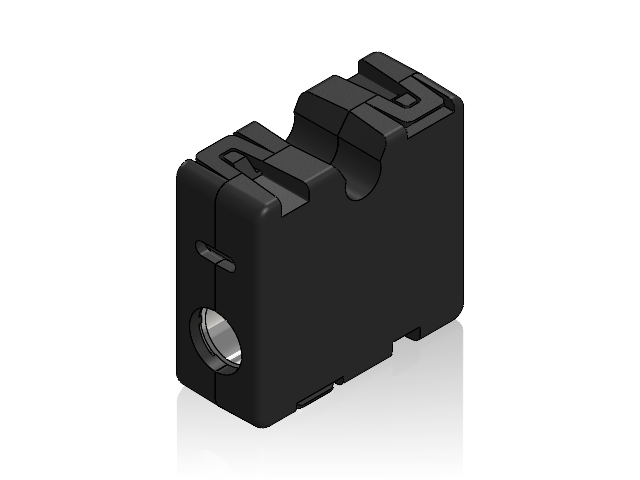
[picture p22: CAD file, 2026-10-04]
建模/sliding block-2.SLDASM
1056-A2P-A (1) (2)-1
1168-B2P-A (2)-1
1255-B2P-A (2)-1

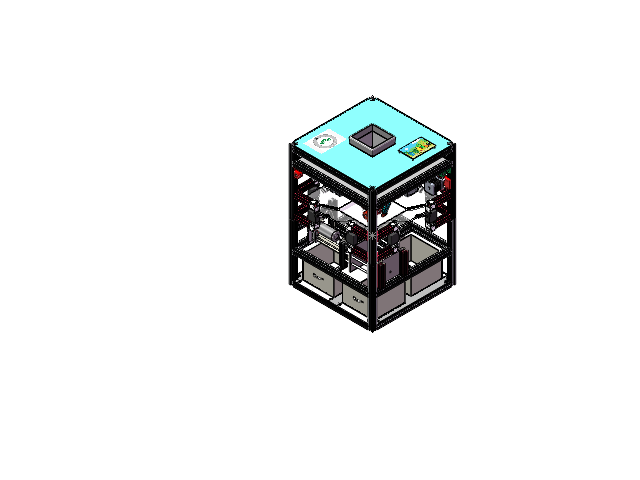
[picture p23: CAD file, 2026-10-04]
建模/装配体2.SLDASM
2020铝型材长360mm(横) x 17
2020铝型材长360mm（竖） x 4
脚码 x 5
2020铝型材长200mm（竖） x 4
底板电机支架
底部舵机固定
底盘电机 x 3
底盘电机舵 x 3
电机架
42BYGH0425(步进电机) x 2
GT2 M8_2 x 8
shaft x 3
机械臂承接架
铝型材2020长100（护板） x 18
长款舵机固定 x 8
挡板固定 x 8
护板 x 4
压缩档板 x 2
2020铝型材长压缩架70mm（竖） x 3
2020铝型材长170mm(横) x 3
步进电机支架（打印件）
步进电机支架2
托盘
MG995舵机(压缩挡板舵机) x 8
舵机铝型材支架 x 16
y-axis rear left（打印件）
x-axis rear left(打印件)
x-axis rear right（打印件）
y-axis rear right（打印件）
x-axis front right（打印件）
y-axis front right（打印件）
x-axis front left（打印件）
y-axis front left(打印件)
8mm光轴（长400mm） x 4
双头皮带轮滑轮 x 2
步进电机支撑块 x 2
固定夹具上
固定夹具下
固定夹具中
直线轴承-标准型_LBLL6 x 2
1056-A2P-A (1) (2)-1 x 4
1168-B2P-A (2)-1 x 4
6mm光轴长349.4mm
1255-B2P-A (2)-1 x 4
6mm光轴长323.71mm
垂直舵机支架
____996.STEP
____-M3-28.STEP x 2
____-M3-18.STEP x 2
____-M3-12.STEP x 2
____-M3-6.STEP x 4
____________.STEP
____3-8-2.STEP x 2
____-dk.STEP x 2
FAE2__-________.STEP
FAE2__-________-0.STEP
FAE2______________.STEP x 2
________M3.STEP x 7
夹层板
平底四角小推杆（行程100）.stp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

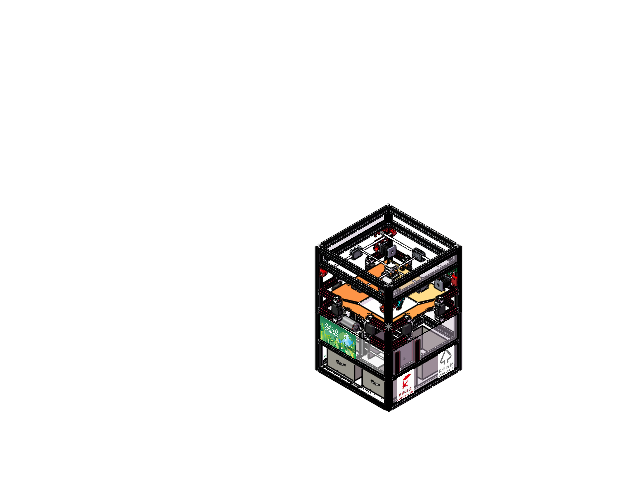
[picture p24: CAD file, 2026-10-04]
建模/第五版.SLDASM
2020铝型材长360mm(横) x 17
2020铝型材长360mm（竖） x 4
脚码 x 5
2020铝型材长200mm（竖） x 4
底板电机支架
底部舵机固定
底盘电机 x 3
底盘电机舵 x 3
电机架
42BYGH0425(步进电机) x 2
GT2 M8_2 x 8
shaft x 3
机械臂承接架
铝型材2020长100（护板） x 18
长款舵机固定 x 8
挡板固定 x 8
护板 x 4
压缩档板 x 2
板
2020铝型材长压缩架70mm（竖） x 3
2020铝型材长170mm(横) x 3
步进电机支架（打印件）
步进电机支架2
托盘
MG995舵机(压缩挡板舵机) x 8
舵机铝型材支架 x 16
y-axis rear left（打印件）
x-axis rear left(打印件)
x-axis rear right（打印件）
y-axis rear right（打印件）
x-axis front right（打印件）
y-axis front right（打印件）
x-axis front left（打印件）
y-axis front left(打印件)
8mm光轴（长400mm） x 4
双头皮带轮滑轮 x 2
步进电机支撑块 x 2
固定夹具上
固定夹具下
固定夹具中
直线轴承-标准型_LBLL6 x 2
1056-A2P-A (1) (2)-1 x 4
1168-B2P-A (2)-1 x 4
6mm光轴长349.4mm
1255-B2P-A (2)-1 x 4
6mm光轴长323.71mm
垂直舵机支架
____996.STEP
____-M3-18.STEP
____________.STEP
____3-8-2.STEP
____-dk.STEP x 2
FAE2__-________.STEP
FAE2__-________-0.STEP
FAE2______________.STEP x 2
平底四角小推杆（行程100）.stp
垃圾桶箱体 x 4
6mm光轴长176.1mm(压缩) x 6
压缩机构地板
滑块_左 x 4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

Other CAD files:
建模/sliding block-3.SLDASM
建模/相关资料/工程图333.dwg
建模/按钮.SLDPRT
建模/外层挡板2.SLDPRT
建模/2020铝型材长170mm(横).SLDPRT
建模/2020铝型材长200mm（竖）.SLDPRT
建模/2020铝型材长360mm(横).SLDPRT
建模/2020铝型材长360mm（竖）.SLDPRT
建模/2020铝型材长压缩架70mm（竖）.SLDPRT
建模/42BYGH0425(步进电机).SLDPRT
建模/6mm光轴长176.1mm(压缩).SLDPRT
建模/6mm光轴长323.71mm.SLDPRT
建模/6mm光轴长349.4mm.SLDPRT
建模/8mm光轴（长400mm）.SLDPRT
建模/GT2 M8_2.SLDPRT
建模/MGN9线轨400.3.SLDPRT
建模/shaft.SLDPRT
建模/x-axis front left（打印件）.SLDPRT
建模/x-axis rear right（打印件）.SLDPRT
建模/y-axis front left(打印件).SLDPRT
建模/y-axis front right（打印件）.SLDPRT
建模/y-axis rear left（打印件）.SLDPRT
建模/y-axis rear right（打印件）.SLDPRT
建模/下底固定板.SLDPRT
建模/下底固定板1.SLDPRT
建模/侧板.SLDPRT
建模/侧板2.SLDPRT
建模/分类挡板2.SLDPRT
建模/压缩机构地板.SLDPRT
建模/压缩档板.SLDPRT
建模/双头皮带轮滑轮.SLDPRT
建模/固定夹具上.SLDPRT
建模/固定夹具下.SLDPRT
建模/固定夹具中.SLDPRT
建模/垃圾桶箱体.SLDPRT
建模/外层挡板.SLDPRT
建模/底板电机支架.SLDPRT
建模/底盘电机.SLDPRT
建模/底盘电机舵.SLDPRT
建模/底部舵机固定.SLDPRT
建模/感应器.SLDPRT
建模/护板.SLDPRT
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

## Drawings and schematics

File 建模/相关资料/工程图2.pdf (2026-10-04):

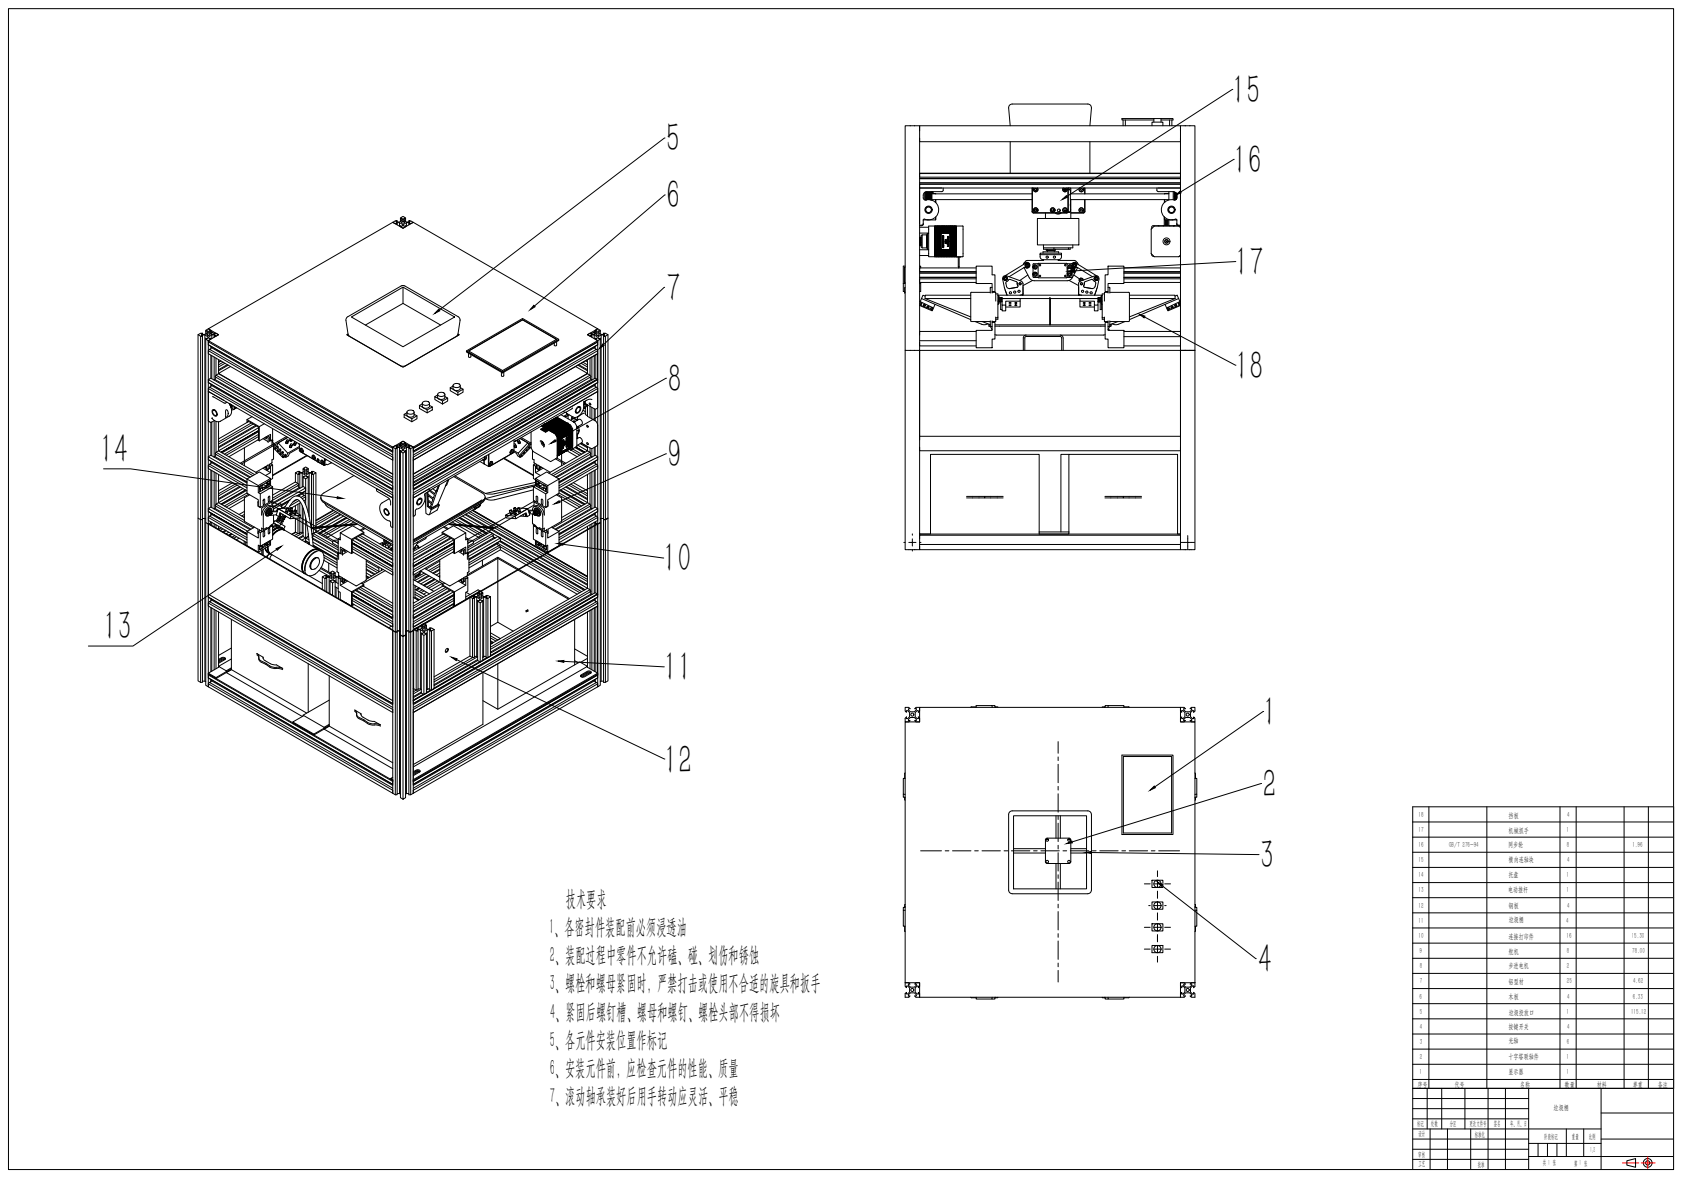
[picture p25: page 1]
机械抓手; 同步轮; 横向连轴块; 电动推杆; 垃圾桶; 连接打印件; 显示器; 1 技术要求 1、各密封件装配前必须浸透油 2、装配过程中零件不允许磕、碰、划伤和锈蚀 3、螺栓和螺母紧固时，严禁打击或使用不合适的旋具和扳手 4、紧固后螺钉槽、螺母和螺钉、螺栓头部不得损坏 5、各元件安装位置作标记 6、安装元件前，应检查元件的性能、质量

8 | 步进电机 | 2

7 | 铝型材 | 25 | 4.62

5 | 垃圾投放口 | 1 | 115.12

4 | 按键开关 | 4

3 | 十字塔联轴件 光轴 | 1 6 2

标记 | 处数 | 分区 | 更改文件号 | 签名 | 年、月、日
标准化 | | | 阶段标记 | 重量 | 比例 设计

审核
工艺 | 批准

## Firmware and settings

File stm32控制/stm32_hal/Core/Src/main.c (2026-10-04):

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
/* Includes ------------------------------------------------------------------*/
#include "main.h"
#include "can.h"
#include "dma.h"
#include "tim.h"
#include "usart.h"
#include "gpio.h"

/* USER CODE BEGIN Includes */
#include "sys.h"
uint16_t strat_x=220;
uint16_t end_x=480;   //x_260
uint16_t start_y=125; 
uint16_t end_y=390;   //y_265
float x_b=4.7;
float x_e=0.9;//3.8
float y_b=0;
float y_e=-3.5;//3.5
float x_count=4.5;
float y_count=4.5;

uint16_t n_0=0;//YH
uint16_t n_1=0;//KHS
uint16_t n_2=0;//CY
uint16_t n_3=0;//QT
uint16_t x1=1;

uint16_t angle_0=130;//nsz
uint16_t angle_1=130;//qian118(55)

uint16_t angle_2=120;//xiao:95-138
uint16_t angle_3=152;//shang60-140
uint16_t angle_4=250;//shun50-147

uint16_t angle_5=140;//shang125:160
uint16_t angle_6=125;//shang110:145
uint16_t angle_7=170;//shang150:189
uint16_t angle_8=70;//shang60:95

uint8_t cam_flag=0;
uint8_t hmi_flag=0;
/* USER CODE END Includes */


void SystemClock_Config(void);
/**
  * @brief  The application entry point.
  * @retval int
  */
int main(void)
{

  /* MCU Configuration--------------------------------------------------------*/

  /* Reset of all peripherals, Initializes the Flash interface and the Systick. */
  HAL_Init();

  /* Configure the system clock */
  SystemClock_Config();

  /* Initialize all configured peripherals */
  MX_GPIO_Init();
  MX_DMA_Init();
  MX_USART1_UART_Init();
  MX_USART3_UART_Init();
  MX_TIM4_Init();
  MX_CAN1_Init();
  /* USER CODE BEGIN 2 */


	MOTOR_Init();
	PCA9685_Init(50,0);
	for_delay_ms(500);
	usart_rx(3);
	
	
	printf("n4.val=%d\xFF\xFF\xFF",1);
	UART3_SendString("FSSJ");
	
//	Emm_V5_Pos_Control(2, 0, 50, 0, 3200, 0, 1);
//	HAL_Delay(10);
//	Emm_V5_Pos_Control(1, 0, 50, 0, 3200, 0, 1);
//	HAL_Delay(10);
//	Emm_V5_Synchronous_motion(0); 
//	while(can.rxFrameFlag == false){}; 
//	can.rxFrameFlag = false;
//	move(1,1); 

  /* USER CODE END 2 */

  /* Infinite loop */
  /* USER CODE BEGIN WHILE */
  while (1)
  {

	  ///////_fianl_///////
//	  htim4.Instance->CCR2 = 70;
//	  control(2,0);
//	  control(0,100);
//	  for_delay_ms(500);
//	  while(1)
//	  {
//		control(0,1);
//	  }
	  ///////_fianl_///////



	  ///////_begin_///////
	  control(2,0);
	  control(0,100);
	  while(1)
	  {

		  
		  initial();

		  
	  }
	  ///////_begin_///////
	  
	  
	  

	  
    /* USER CODE END WHILE */

    /* USER CODE BEGIN 3 */
  }
  /* USER CODE END 3 */
}

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


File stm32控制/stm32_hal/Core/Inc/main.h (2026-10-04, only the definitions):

#define SDA_Pin GPIO_PIN_7
#define SDA_GPIO_Port GPIOC
#define SCL_Pin GPIO_PIN_8
#define SCL_GPIO_Port GPIOC
#define key_s1_Pin GPIO_PIN_3
#define key_s1_GPIO_Port GPIOB

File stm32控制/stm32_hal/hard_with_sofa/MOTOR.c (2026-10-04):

#include "MOTOR.h"
int counts=0;
//获取光电值
int GD(int i)
{
	int a;
	switch(i)
	{
		case 1:a=GD1;break;
		case 2:a=GD2;break;		
		case 3:a=GD3;break;
		
		default:a=-1;break;
	}
	return a;
}

void MOTOR_Init(void)
{
	HAL_TIM_PWM_Start(&htim4,TIM_CHANNEL_1);
	HAL_TIM_PWM_Start(&htim4,TIM_CHANNEL_2);
	htim4.Instance->CCR1 = 900;
//	htim4.Instance->CCR2 = 50;
	HAL_GPIO_WritePin(GPIOA, GPIO_PIN_8, GPIO_PIN_SET);
	HAL_GPIO_WritePin(GPIOC, GPIO_PIN_9, GPIO_PIN_RESET);
	USER_CAN1_Filter_Init();
	if(HAL_CAN_Start(&hcan1) != HAL_OK) { Error_Handler(); }	
	if(HAL_CAN_ActivateNotification(&hcan1, CAN_IT_RX_FIFO0_MSG_PENDING) != HAL_OK) { Error_Handler(); }
	HAL_Delay(1000);
}

void compress(int comp)
{
	switch(comp)
	{
		case 0:
			HAL_GPIO_WritePin(GPIOC, GPIO_PIN_4, GPIO_PIN_SET);
			HAL_GPIO_WritePin(GPIOC, GPIO_PIN_5, GPIO_PIN_RESET);
			break;
		case 1:
			HAL_GPIO_WritePin(GPIOC, GPIO_PIN_4, GPIO_PIN_SET);
			HAL_GPIO_WritePin(GPIOC, GPIO_PIN_5, GPIO_PIN_RESET);
			break;	
	}
}

void move(float m_x,float m_y)
{
	int direr=0;
	int direr_1=0;
	int direr_2=0;
	
	if      (m_x<0) { direr=0; m_x=-m_x;}
	else if (m_x>0) { direr=1;}
	if      (m_y<0) { direr_1=0; direr_2=1;  m_y=-1.0*m_y;}
	else if (m_y>0) { direr_1=1; direr_2=0;}
	if(m_x!=0)
	{
		Emm_V5_Pos_Control(1, direr, 100, 0,(int)3200*m_x, 0, 1);
		HAL_Delay(10);
		Emm_V5_Pos_Control(2, direr, 100, 0, (int)3200*m_x, 0, 1);
		HAL_Delay(10);
		Emm_V5_Synchronous_motion(0);
		while(1){for_delay_ms(10);counts++;if(counts==(int)( (m_x)*90 )){ counts=0; break;}}; can.rxFrameFlag = false;
	}
	HAL_Delay(10);
	if (m_y!=0)
	{
		Emm_V5_Pos_Control(1, direr_1, 100, 0, (int)(3200*m_y), 0, 1);
		HAL_Delay(10);
		Emm_V5_Pos_Control(2, direr_2, 100, 0, (int)(3200*m_y), 0, 1);
		HAL_Delay(10);
		Emm_V5_Synchronous_motion(0);
		while(1){for_delay_ms(10);counts++;if(counts==(int)( (m_y)*90 )){ counts=0; break;}}; can.rxFrameFlag = false;
		
	}	
}

void assign(int n0,int n1,int n2,int n3,int x1,int x2,int z,int k)//
{
	printf("n0.val=%d\xFF\xFF\xFF",n0);
	printf("n0.val=%d\xFF\xFF\xFF",n0);
	printf("n1.val=%d\xFF\xFF\xFF",n1);
	printf("n2.val=%d\xFF\xFF\xFF",n2);
	printf("n3.val=%d\xFF\xFF\xFF",n3);
	printf("x1.val=%d\xFF\xFF\xFF",x1);
	printf("x2.val=%d\xFF\xFF\xFF",x2);

	switch (z)
	{
		case 0:{printf("t3.txt=\"未完成\"\xFF\xFF\xFF");}break;
		case 1:{printf("t3.txt=\"完成\"\xFF\xFF\xFF");}break;
	}
	switch (k)
	{
		case 1:{printf("t1.txt=\"有害垃圾\"\xFF\xFF\xFF");}break;
		case 2:{printf("t1.txt=\"可回收垃圾\"\xFF\xFF\xFF");}break;
		case 3:{printf("t1.txt=\"厨余垃圾\"\xFF\xFF\xFF");}break;
		case 4:{printf("t1.txt=\"其他垃圾\"\xFF\xFF\xFF");}break;
	}
	

}

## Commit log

2026-10-04 feat: 智能分类垃圾桶系统（STM32F407 + YOLOv5 视觉识别）
    - stm32控制: Keil MDK-ARM 工程 + STM32CubeMX 配置（gongchuang.ioc），含 PCA9685 舵机驱动、Emm_V5 闭环步进 CAN 驱动、视觉数据帧解析与分拣/抓取逻辑
    - 视觉方案: MaixCam 端 YOLOv5 检测与串口通信脚本
    - 建模: SolidWorks 三维模型、装配体与工程图
    - 图片: 整机外观、内部结构、识别效果与演示视频
    - 说明: 详见 README.md；STM32 固件库 Drivers/ 不入库，由 CubeMX 依据 ioc 生成
    [2020铝型材长170mm(横).SLDPRT, 2020铝型材长200mm（竖）.SLDPRT, 2020铝型材长360mm(横).SLDPRT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]
2026-10-04 docs: 视频改用封面图+跳转链接（GitHub 会过滤 video 标签）
2026-10-04 docs: 演示视频改用 B 站链接，移除结构爆炸动画

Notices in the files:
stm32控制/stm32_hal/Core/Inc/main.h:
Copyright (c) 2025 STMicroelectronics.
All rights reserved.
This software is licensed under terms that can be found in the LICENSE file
